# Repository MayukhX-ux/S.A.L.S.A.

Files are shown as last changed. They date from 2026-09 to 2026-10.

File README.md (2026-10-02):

# 🌊 S.A.L.S.A

## Secure Acoustic Ledger for Subsea Autonomy

**Software-Defined Adaptive Low-Power Sonar Transmitter Payload for Autonomous Underwater Vehicles**

### Developed by Team Nexora

---

# 📌 Project Overview

**S.A.L.S.A. is a software-defined, adaptive sonar transmitter payload designed for Autonomous Underwater Vehicles (AUVs).**

Unlike a conventional transmitter that operates using a fixed waveform and transmission configuration, S.A.L.S.A. uses real-time environmental information to dynamically modify its acoustic transmission parameters.

The system follows:

```text
SENSE → ANALYSE → ADAPT → GENERATE → TRANSMIT
```

The current prototype monitors **depth, temperature, and turbidity** using dedicated underwater sensors. These parameters are processed by an **ESP32-based embedded controller**, which calculates an environmental condition value and determines suitable transmission characteristics.

The selected waveform is generated using **Direct Digital Synthesis (DDS)**, transferred through a high-speed DMA-assisted parallel interface, converted into an analog signal using a **12-bit R-2R DAC**, and conditioned through a multi-stage **OPA356 active filter** before being passed toward the external power-amplification and acoustic-transmission section.

---

# ⚡ At a Glance

| Parameter | Current Specification |
| :--- | :--- |
| 🎯 Application | Autonomous Underwater Vehicles (AUVs) |
| 📡 Frequency Range | 100–500 kHz |
| ⚡ Sampling Rate | 4 MS/s |
| 🎚️ DAC Resolution | 12-bit |
| 🔢 DDS Phase Accumulator | 32-bit |
| 🌊 Waveform Types | 5 |
| 🪟 Digital Windows | Hamming / Hann / Blackman |
| 🧮 Sine LUT | 4096 entries |
| 🌡️ Environmental Inputs | Depth / Temperature / Turbidity |
| 🔌 DAC Architecture | R-2R Ladder |
| 🧠 Controller | ESP32-WROOM-32 |
| 🔄 High-Speed Output | I2S0 Parallel + DMA |
| 🎛️ Analog Filter | Multi-stage OPA356 |
| 👥 Development Team | Team Nexora |

---

# 🧠 System Architecture

```text
Environmental Sensors
        ↓
ESP32 Environmental Analysis
        ↓
Adaptive Algorithm
        ↓
Waveform Selection
        ↓
DDS + LUT
        ↓
I2S0 Parallel + DMA
        ↓
SN74LVC541A Digital Buffers
        ↓
12-bit R-2R DAC
        ↓
OPA356 Filter Stage 1
        ↓
OPA356 Filter Stage 2
        ↓
PA Interface
        ↓
Power Amplifier
        ↓
Matching Network
        ↓
Underwater Acoustic Transducer
```

---

# 🌊 Environmental Sensing

## 🌫️ Turbidity — SEN0710

The **DFRobot SEN0710 industrial turbidity sensor** provides underwater turbidity measurements.

The sensor communicates with the ESP32 through **RS-485 Modbus RTU** using a **MAX3485E** transceiver.

```text
SEN0710
   │ RS-485
   ▼
MAX3485E
   │ UART
   ▼
ESP32
```

| Parameter | Specification |
| :--- | :--- |
| Measurement Range | 0–1000 NTU |
| Interface | RS-485 |
| Protocol | Modbus RTU |
| Supply | 10–30 V |
| Protection | IP68 |

## 🌊 Depth + Temperature — MS5837-30BA

The **MS5837-30BA** provides pressure-based depth information together with temperature measurement through **I2C**.

```text
MS5837-30BA
      │
      ├── SDA → ESP32 GPIO32
      └── SCL → ESP32 GPIO33
```

---

# 🔌 RS-485 Interface

```text
                 MAX3485E

SEN0710 A ───────── A
SEN0710 B ───────── B

RO ───────────────── ESP32 RX
DI ───────────────── ESP32 TX

DE + /RE ─────────── ESP32 Direction Control
```

This provides a differential communication interface between the underwater sensor and embedded controller.

---

# 🧩 Adaptive Decision Algorithm

The prototype considers:

```text
Turbidity
    +
Depth
    +
Temperature Stress
    ↓
Environmental Condition E
    ↓
Adaptive Transmission Parameters
```

A representative prototype model is:

```text
E = 0.45 × Turbidityₙ
  + 0.30 × Depthₙ
  + 0.25 × TemperatureStress
```

The resulting environmental condition is used to modify:

- Frequency
- Bandwidth
- Centre frequency
- Pulse duration
- Signal amplitude
- Waveform type

> Note: The current adaptive relationship is a prototype heuristic intended for demonstration and experimental validation. It is not presented as a universal underwater acoustic propagation law.

---

# 🎛️ Adaptive Transmission

The prototype dynamically modifies the waveform according to the calculated environmental condition.

```text
LOW E        → Wider bandwidth / higher-frequency operation
MEDIUM E     → Moderate adaptive configuration
HIGH E       → Narrower bandwidth / lower centre-frequency operation
```

---

# 🌊 Waveform Engine

| Waveform | Description |
| :--- | :--- |
| **LFM Up-Chirp** | Frequency increases throughout the pulse |
| **LFM Down-Chirp** | Frequency decreases throughout the pulse |
| **CW Pulse** | Fixed-frequency sinusoidal pulse |
| **Barker-7** | Phase-coded waveform |
| **Geometric Sweep** | Non-linear frequency sweep |

### Barker-7 Sequence

```text
+1   +1   +1   -1   -1   +1   -1
```

---

# 📡 Frequency & Bandwidth Adaptation

The prototype operates across:

```text
100 kHz ─────────────────────────────── 500 kHz
```

A representative adaptive model is:

```text
Bandwidth = 400 kHz − 300 kHz × E

Centre Frequency = 300 kHz − 100 kHz × E
```

At low environmental condition:

```text
E ≈ 0
Operating Band ≈ 100–500 kHz
```

At high environmental condition:

```text
E ≈ 1
Operating Band ≈ 150–250 kHz
```

These values demonstrate the software-controlled adaptation mechanism and can be refined through future underwater experiments.

---

# 🧮 Direct Digital Synthesis

S.A.L.S.A. generates its waveform using **Direct Digital Synthesis (DDS)**.

```text
32-bit Phase Accumulator
        +
4096-entry Sine LUT
        +
4 MS/s Sampling Rate
        ↓
Digital Waveform Samples
```

The phase increment is:

```text
ΔP = (f / fs) × 2³²
```

For example:

```text
f  = 500 kHz
fs = 4 MHz

ΔP = 536,870,912
```

This allows precise digital frequency control without continuously calculating trigonometric functions.

---

# 🪟 Digital Windowing

S.A.L.S.A. supports:

| Window | Purpose |
| :--- | :--- |
| **Hamming** | Default waveform window |
| **Hann** | Smooth pulse shaping |
| **Blackman** | Stronger sidelobe suppression |

---

# ⚡ High-Speed DAC Output

```text
Waveform Buffer
      ↓
DMA Engine
      ↓
I2S0 Parallel
      ↓
SN74LVC541A
      ↓
12-bit R-2R DAC
```

The target digital sample rate is **4 MS/s**.

---

# 🔢 12-bit R-2R DAC

The prototype uses a discrete **12-bit R-2R ladder DAC**.

```text
R  = 10 kΩ
2R = 20 kΩ
```

Ideal relationship:

```text
VOUT = VREF × CODE / 4096
```

With a 3.3 V reference:

```text
Ideal LSB ≈ 0.806 mV
```

The digital bits are driven through **SN74LVC541A** buffers.

---

# 🎯 Precision DAC Reference — ADR4533

The R-2R DAC uses an **ADR4533 precision 3.3 V voltage reference**.

```text
+5V Analog
    ↓
ADR4533
    ↓
DAC_VREF
    ↓
R-2R Ladder
```

Local bypass capacitors support reference stability and noise performance.

---

# 🎚️ Analog Filter Chain

The raw DAC output is passed through two active filter stages using **OPA356**.

```text
12-bit R-2R DAC
       ↓
OPA356 Stage 1
R1 = 1 kΩ
R2 = 1 kΩ
C1 = 249 pF
C2 = 210 pF
       ↓
OPA356 Stage 2
R3 = 1 kΩ
R4 = 1 kΩ
C3 = 590 pF
C4 = 86.6 pF
       ↓
FILTER_OUT
```

The filter stages condition the DAC waveform and suppress unwanted high-frequency components.

---

# 🔌 Power Amplifier Interface

The filtered waveform is not intended to directly drive the underwater transducer.

```text
FILTER_OUT
    ↓
PA INPUT
    ↓
POWER AMPLIFIER
    ↓
MATCHING NETWORK
    ↓
UNDERWATER TRANSDUCER
```

The exact amplifier and matching network depend on the selected transducer's impedance, resonance, capacitance, voltage and power requirements.

---

# 🔌 Complete Circuit Schematic

<div align="center">

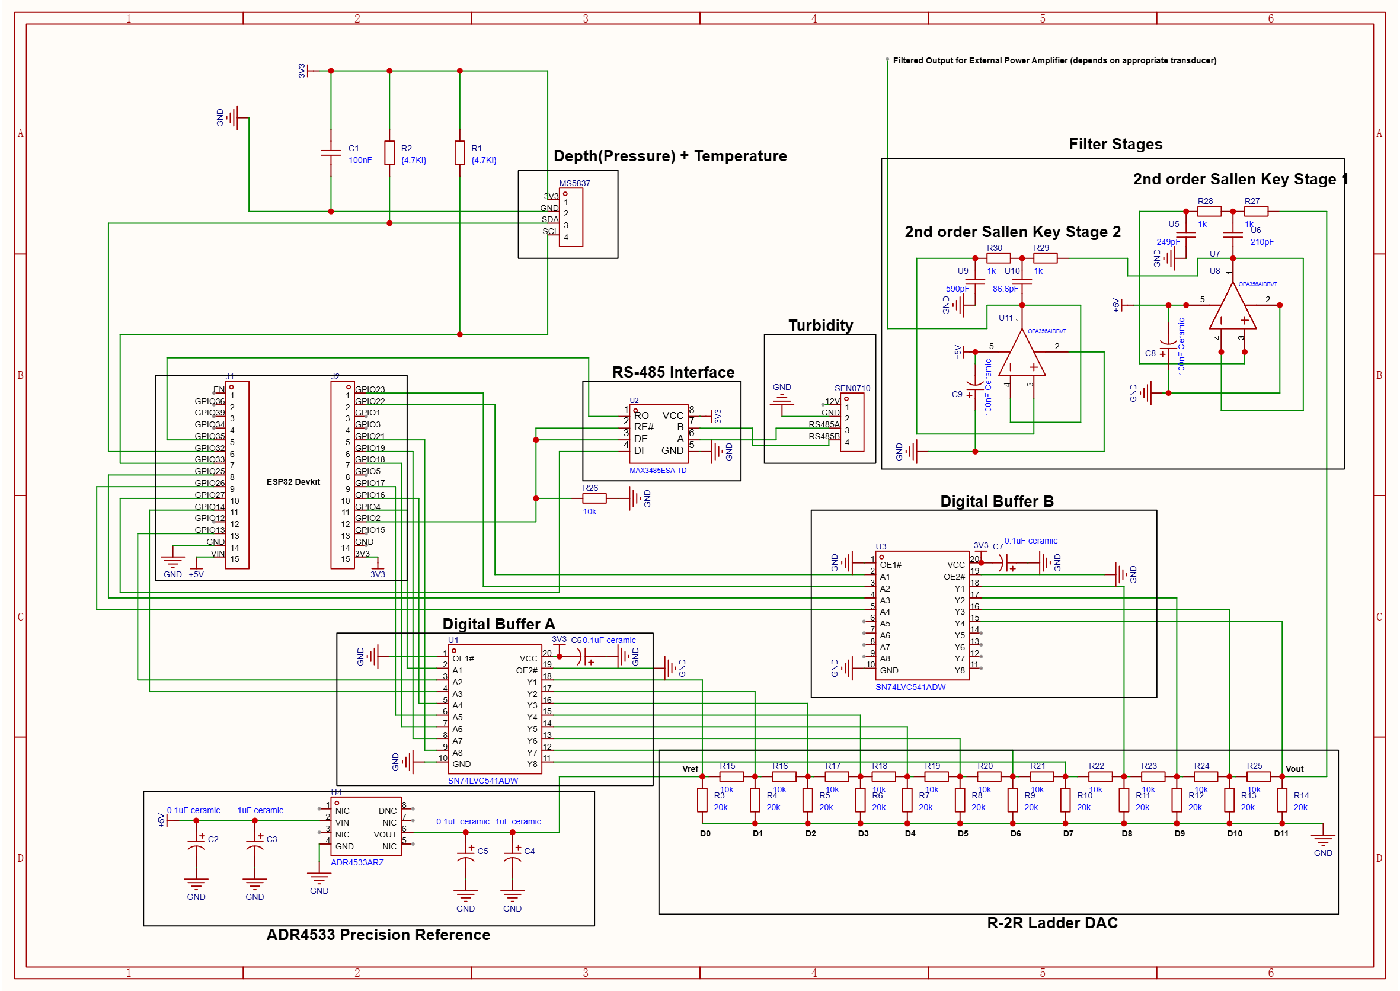
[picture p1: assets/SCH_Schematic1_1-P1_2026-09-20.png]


<i>Complete S.A.L.S.A. hardware schematic.</i>

</div>

---

# 📈 Waveform Output

<div align="center">

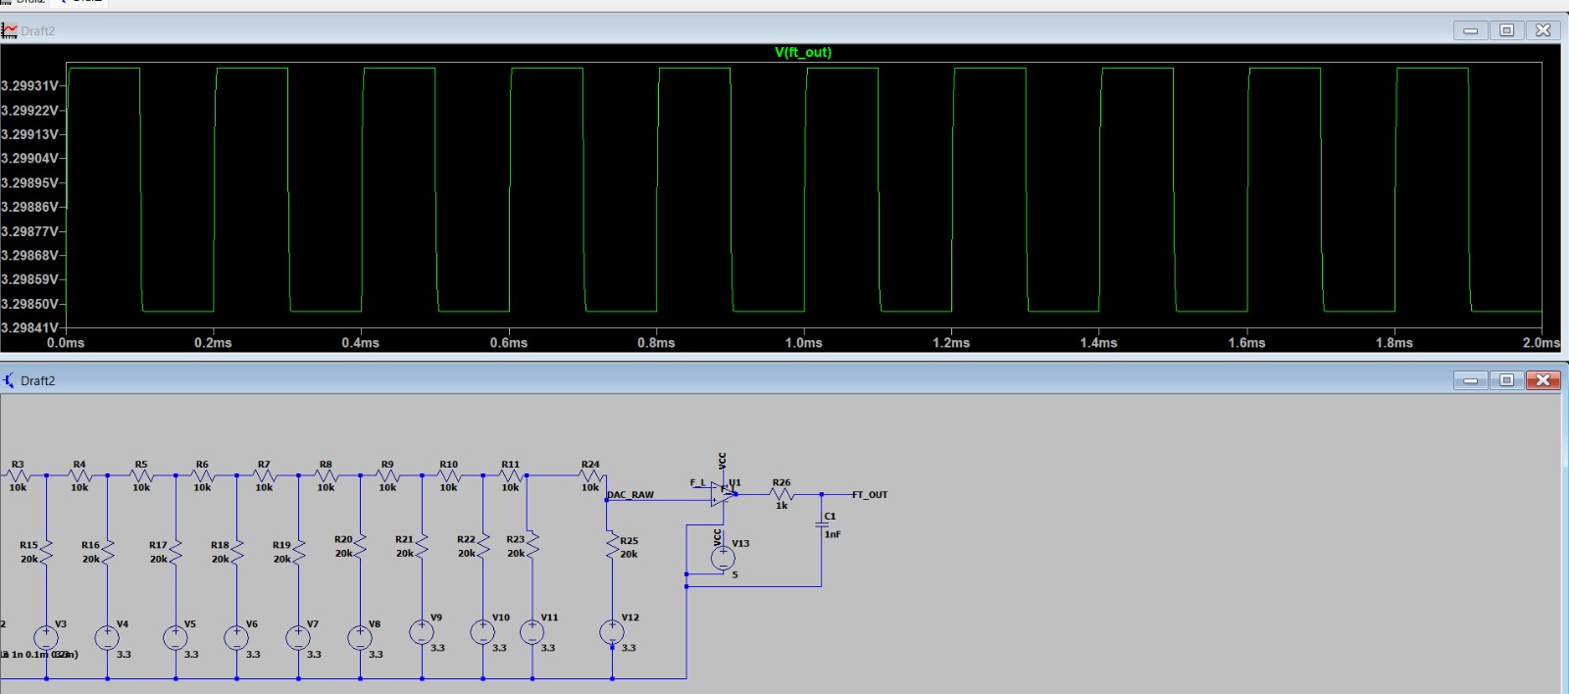
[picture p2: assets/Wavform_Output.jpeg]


<i>S.A.L.S.A. waveform output demonstrating the generated sonar signal.</i>

</div>

---

# 🧱 Hardware Architecture

```text
ESP32
  │
  ├── Environmental Sensing
  ├── Adaptive Algorithm
  ├── DDS + LUT
  └── I2S0 + DMA
          ↓
SN74LVC541A
          ↓
12-bit R-2R DAC
          ↓
OPA356 Filter 1
          ↓
OPA356 Filter 2
          ↓
PA Interface
          ↓
Power Amplifier
          ↓
Matching Network
          ↓
Underwater Transducer
```

---

# 🧠 Firmware Architecture

```text
SALSA-Firmware/
│
├── CMakeLists.txt
├── sdkconfig.defaults
│
└── main/
    ├── main.cpp
    ├── config.h
    ├── ms5837.h
    ├── ms5837.cpp
    ├── sen0710.h
    ├── sen0710.cpp
    ├── adaptive.h
    ├── adaptive.cpp
    ├── dds.h
    ├── dds.cpp
    ├── waveform.h
    ├── waveform.cpp
    ├── dac_parallel.h
    └── dac_parallel.cpp
```

---

# ⚙️ Firmware Processing Flow

```text
INITIALIZE SYSTEM
       ↓
INITIALIZE SENSORS
       ↓
INITIALIZE DDS + LUT
       ↓
INITIALIZE I2S0 + DMA
       ↓
READ ENVIRONMENT
       ↓
CALCULATE ENVIRONMENTAL CONDITION
       ↓
SELECT WAVEFORM
       ↓
CALCULATE DDS PARAMETERS
       ↓
GENERATE SAMPLES
       ↓
APPLY WINDOW
       ↓
DMA → I2S0
       ↓
12-bit R-2R DAC
       ↓
ANALOG FILTER
       ↓
PA / TRANSDUCER
       ↓
REPEAT
```

---

# 🧰 Technology Stack

| Category | Technology |
| :--- | :--- |
| Microcontroller | ESP32-WROOM-32 |
| Firmware | C/C++ |
| Development | ESP-IDF |
| Waveform Generation | DDS |
| Sine LUT | 4096 Entries |
| Sample Rate | 4 MS/s |
| High-Speed Interface | I2S0 Parallel + DMA |
| DAC | 12-bit R-2R Ladder |
| DAC Reference | ADR4533 |
| Digital Buffer | SN74LVC541A |
| Analog Amplifier | OPA356 |
| Depth Sensor | MS5837-30BA |
| Turbidity Sensor | DFRobot SEN0710 |
| RS-485 Transceiver | MAX3485E |
| Sensor Communication | I2C + RS-485 Modbus RTU |
| Signal Processing | Embedded DSP |
| Waveforms | LFM / CW / Barker-7 / Geometric |
| Windowing | Hamming / Hann / Blackman |

---

# 📊 System Specifications

| Specification | Current Design |
| :--- | :--- |
| Operating Frequency | 100–500 kHz |
| Sampling Rate | 4 MS/s |
| DAC Resolution | 12-bit |
| DDS Phase Accumulator | 32-bit |
| Sine Lookup Table | 4096 entries |
| Waveform Types | 5 |
| Window Functions | 3 |
| Environmental Inputs | Depth / Temperature / Turbidity |
| Depth Interface | I2C |
| Turbidity Interface | RS-485 Modbus RTU |
| DAC Architecture | R-2R |
| DAC Resistors | 10 kΩ / 20 kΩ |
| DAC Reference | ADR4533 3.3 V |
| Digital Buffer | SN74LVC541A |
| Analog Filter | Two-stage OPA356 |
| High-Speed Output | I2S0 Parallel + DMA |
| Primary Controller | ESP32 |
| External PA | Modular |
| Acoustic Transducer | Modular |
| Development Team | Team Nexora |

---

# 🧪 Current Prototype Validation

| Module | Status |
| :--- | :---: |
| ESP32 Control | ✅ |
| MS5837 Depth Interface | ✅ |
| MS5837 Temperature Interface | ✅ |
| SEN0710 Turbidity Interface | ✅ |
| MAX3485E RS-485 Interface | ✅ |
| Adaptive Processing | ✅ |
| DDS Waveform Generation | ✅ |
| 4096-Entry Sine LUT | ✅ |
| 32-bit Phase Accumulator | ✅ |
| I2S0 Parallel Output | ✅ |
| DMA-Based Sample Transfer | ✅ |
| 12-bit R-2R DAC | ✅ |
| ADR4533 Precision Reference | ✅ |
| SN74LVC541A Buffering | ✅ |
| OPA356 Filter Stage 1 | ✅ |
| OPA356 Filter Stage 2 | ✅ |
| Waveform Output | ✅ |
| External Power Amplifier | Modular |
| Matching Network | Modular |
| Underwater Transducer | Future Integration |

---

# 💡 Key Innovation

S.A.L.S.A. moves beyond a fixed waveform transmitter by making transmission parameters software-controlled and environmentally aware.

```text
UNDERWATER ENVIRONMENT
          ↓
DEPTH / TEMPERATURE / TURBIDITY
          ↓
ENVIRONMENTAL CONDITION ANALYSIS
          ↓
ADAPTIVE PARAMETERS
          ↓
SOFTWARE-DEFINED WAVEFORM ENGINE
          ↓
ANALOG TRANSMISSION
```

The system connects real-time environmental measurements with physical acoustic waveform generation, creating a flexible platform for adaptive underwater transmission research.

---

# 🔭 Future Development

Future development can include:

- Experimental underwater validation
- Integration with an actual underwater transducer
- Power amplifier optimisation
- Transducer-specific impedance matching
- Closed-loop acoustic feedback
- Salinity and conductivity sensing
- Ambient acoustic noise measurement
- Adaptive received-signal analysis
- More advanced waveform optimisation
- Data-driven adaptive algorithms
- FPGA/DSP-based high-performance implementation
- Higher-speed precision DAC
- Full AUV payload integration
- Autonomous mission-level control

A future closed-loop architecture could evolve toward:

```text
ENVIRONMENT
     ↓
SENSING
     ↓
ADAPTIVE TRANSMISSION
     ↓
ACOUSTIC SIGNAL
     ↓
TARGET / ENVIRONMENT
     ↓
RECEIVED ECHO
     ↓
SIGNAL QUALITY ANALYSIS
     ↓
NEXT TRANSMISSION
```

---

# 👥 Team Nexora

| Member | Role | Department | Responsibility |
| :---: | :--- | :---: | :--- |
| Mayukh Mondal | Team Lead & Firmware Architect | CSE | System Design & Integration |
| Bhavya Kumari | Embedded Systems Engineer | ET&T | Microcontroller & Embedded Development |
| Kashish Shariff | Signal Processing Specialist | ET&T | Filter Design & DSP |
| Omkar Sahu | Software & Simulation Engineer | CSE | Algorithm Development |
| Kanak Narware | UI/UX & Data Analyst | CSE | Visualization & Data Presentation |
| Shubham Mishra | Mechanical Design Engineer | Mech | Mechanical Design & Integration |

---

# 🗂️ Project Structure

```text
S.A.L.S.A/
│
├── assets/
│   ├── SCH_Schematic1_1-P1_2026-09-20.png
│   ├── Wavform_Output.jpeg
│   └── Team Logo.png
│
├── main/
│   ├── main.cpp
│   ├── config.h
│   ├── ms5837.cpp
│   ├── ms5837.h
│   ├── sen0710.cpp
│   ├── sen0710.h
│   ├── adaptive.cpp
│   ├── adaptive.h
│   ├── dds.cpp
│   ├── dds.h
│   ├── waveform.cpp
│   ├── waveform.h
│   ├── dac_parallel.cpp
│   └── dac_parallel.h
│
├── README.md
│
└── source/
    └── ...
```

---

# ▶️ S.A.L.S.A. Project Video

<div align="center">

<a href="https://youtu.be/eq3fUiAaMew">

Watch S.A.L.S.A. on YouTube

</a>

### **▶ Watch the S.A.L.S.A. Project Video**

**100–500 kHz | 12-bit DAC | 4 MS/s | 5 Waveforms**

*Built for adaptive underwater acoustic transmission.*

</div>

---

<div align="center">

## 🌊 S.A.L.S.A.

### Secure Acoustic Ledger for Subsea Autonomy

**Developed by Team Nexora**

**Adaptive • Acoustic • Autonomous**

**Smart India Hackathon 2026**

**Robotics & Drones Theme**

</div>

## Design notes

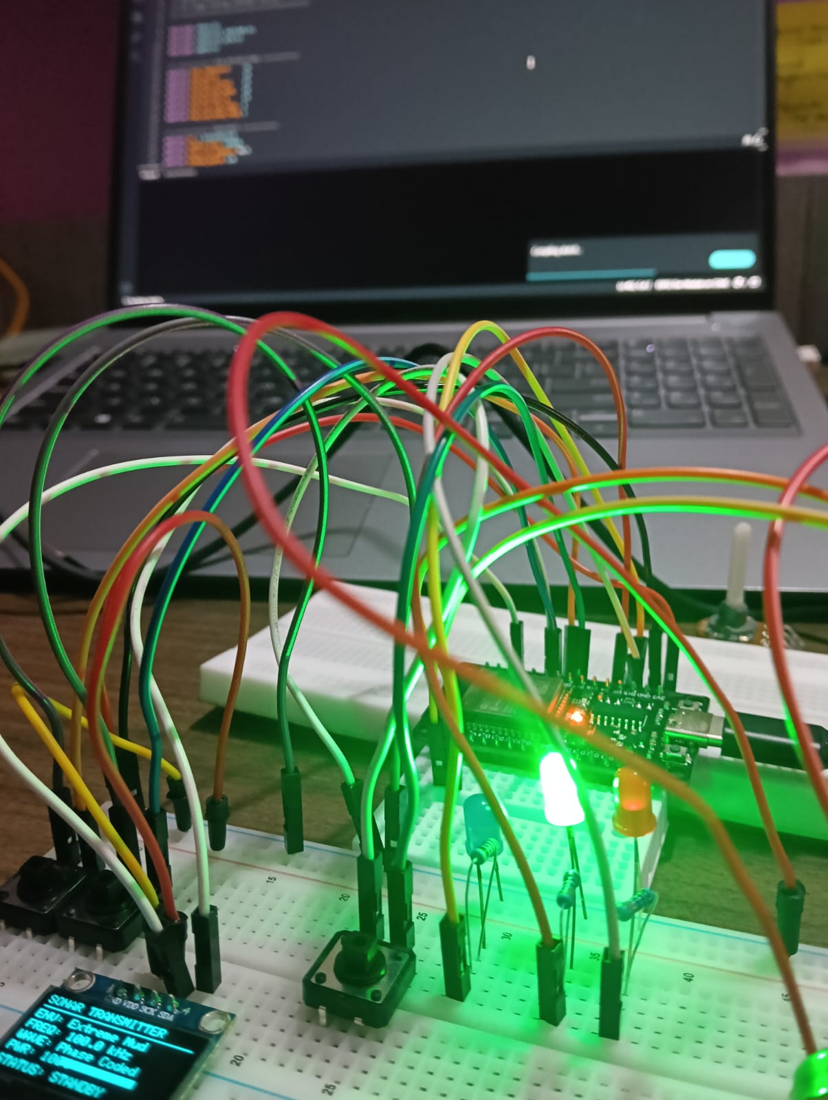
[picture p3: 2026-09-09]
assets/Initial Prototype.jpeg

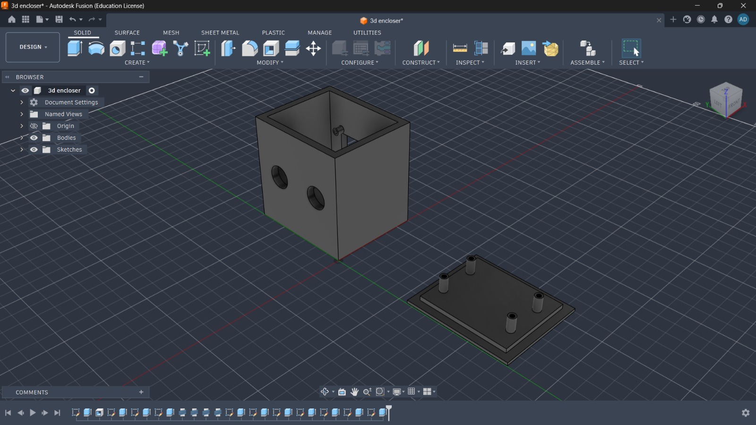
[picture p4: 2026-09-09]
assets/3D enclosure_02.jpeg

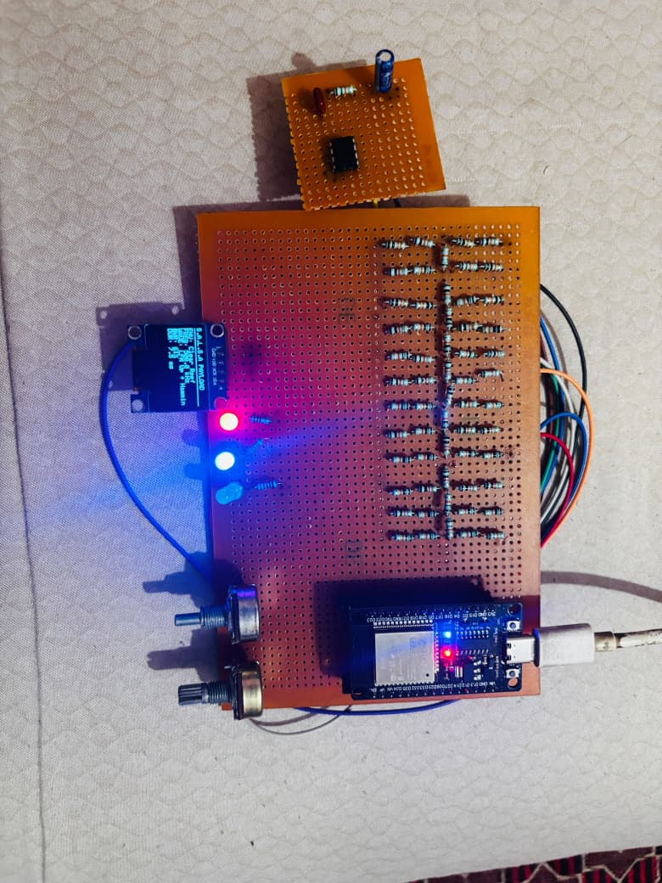
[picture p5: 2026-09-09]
assets/Prototype_v2.jpeg

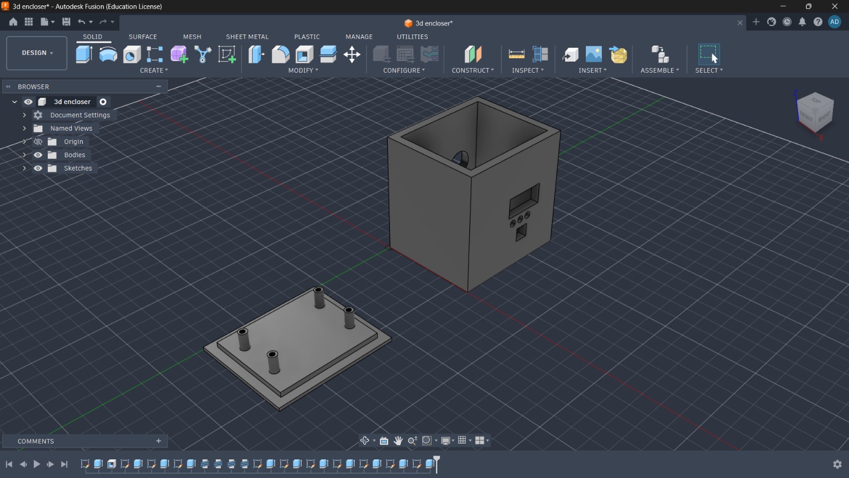
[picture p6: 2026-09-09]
assets/3D enclosure.jpeg

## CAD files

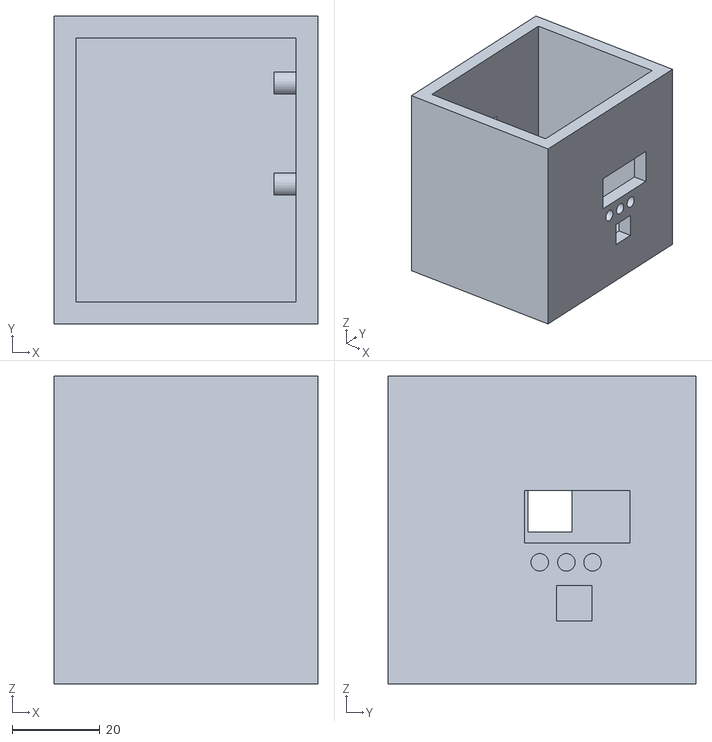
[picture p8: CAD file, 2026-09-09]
3D Enclosure/box_.stl
60.0 x 70.0 x 70.0

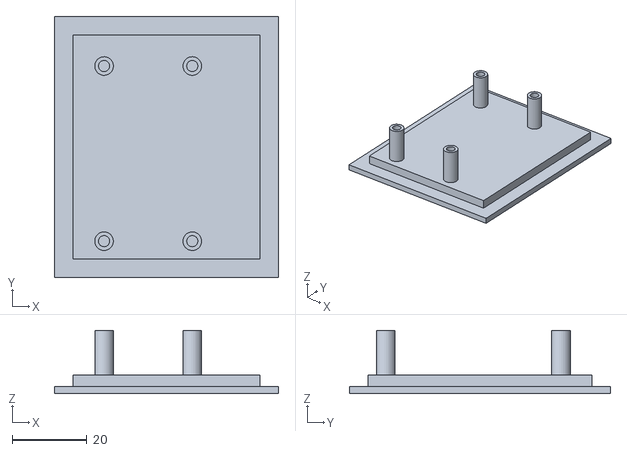
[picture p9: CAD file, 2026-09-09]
3D Enclosure/Untitled.stl
60.0 x 70.0 x 17.0

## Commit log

2026-09-09 Update image source for 3D enclosure in README
2026-09-09 Create Enclosure Design
2026-10-02 Simulation and schematic uploaded
